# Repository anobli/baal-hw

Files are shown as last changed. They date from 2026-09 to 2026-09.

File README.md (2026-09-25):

# Beal

Beal is a **LoRa valve-control proxy** that retrofits an existing irrigation
controller with remote, wire-free zone control.

## Why

Irrigation controllers are typically wire-only: reaching a new zone, or a
valve far from the controller box, means trenching new low-voltage wiring
across a working field — labor-intensive and disruptive.

Beal solves that wiring problem: clip a **RX** unit onto the existing
controller (no new wiring, no controller replacement) and place **TX** units
directly at the valves; they talk over LoRa, so control reaches valves
without trenching.

## How it works

Two dedicated boards make up one system:

| Board | Role | What it does |
| --- | --- | --- |
| [**Beal-Rx**](Beal-Rx/README.md) | Input | Clips onto the existing controller's zone-output wiring, senses which zone it's energizing, and reports over LoRa. Acts as the LoRa coordinator. |
| [**Beal-TX**](Beal-TX/README.md) | Output | Lives out at the valves, powered by its own battery + solar supply. Drives valve solenoids on command from Beal-Rx. Acts as a LoRa peer. |

```mermaid
flowchart TD
    VC["Existing valve controller<br/>(zone outputs)"] -->|wired, no new cabling| RX["Beal-Rx<br/>LoRa coordinator"]
    RX -->|LoRa P2P, star topology| TX1["Beal-TX #1<br/>LoRa peer"]
    RX -->|LoRa P2P, star topology| TX2["Beal-TX #2<br/>LoRa peer"]
    TX1 -->|wired| V1["Valves — zone A"]
    TX2 -->|wired| V2["Valves — zone B"]
```

The link between Beal-Rx and Beal-TX units is point-to-point LoRa, not
LoRaWAN: a custom, open-source stack with a star topology. Beal-Rx is the
coordinator — it's where commands originate and it's already the central
device by virtue of being wired to the existing controller. Beal-TX units are
peer nodes that take commands from it. LoRaWAN is deliberately avoided for
now — it would require network-server infrastructure disproportionate to
stand up and operate for this product.

## Repository layout

| Folder | What it is |
| --- | --- |
| [`Beal-Rx/`](Beal-Rx/README.md) | Input board: KiCad project, schematics, PCB. |
| [`Beal-TX/`](Beal-TX/README.md) | Output board: KiCad project, schematics, PCB. |
| `Beal-Common/` | Reusable elements shared between boards — currently footprints, with symbol libraries and design blocks planned. |

Schematic PDFs and BOMs are generated automatically on every push via
[`.github/workflows/kicad-schematic-pdf.yml`](.github/workflows/kicad-schematic-pdf.yml).

## What's next: Beal Controller

Both boards share the same LoRa-E5-centric approach, which is also the seed
for a future third board — tentatively **Beal Controller**. It would be a
smart irrigation controller with its own valve outputs and smart features
(weather-driven scheduling, ET0 computation, local web UI), while still able
to control remote valves over LoRa through a Beal-TX unit — replacing the
third-party controller entirely instead of just retrofitting it. This is a
future direction, not yet designed.

## License

Hardware design files are licensed under the
[CERN Open Hardware Licence Version 2 - Strongly Reciprocal](LICENSE).

## Open items

- [ ] Battery chemistry/capacity for the Beal-TX power pack — not yet sized.
- [ ] Enclosure — to do, no design started.
- [ ] Regulatory/certification path for the radio — not started; complicated
      by the use of a custom (non-LoRaWAN) PHY/MAC stack.
- [ ] Unit cost target (below 250 € incl. VAT) — needs re-costing against the
      current RX/TX design.
- [ ] Beal Controller — not designed yet; see above.

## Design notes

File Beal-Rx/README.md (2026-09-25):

# Beal-Rx — input board

Beal-Rx clips onto an existing irrigation controller's zone-output wiring,
senses which zone it's energizing, and reports that over LoRa to one or more
[Beal-TX](../Beal-TX/README.md) units. It is the LoRa coordinator of a Beal
system — it's where commands originate, and it's already the natural central
device since it's the one wired to the existing controller.

The schematic is split into three sheets: **Inputs**, **Radio**, **Power**.

## Inputs (`io_ext.kicad_sch`)

- 12 sense channels, each isolated from the field wiring by an opto-isolator
  (3× LTV-844S, 4 channels each). This gives galvanic isolation from whatever
  the existing controller puts on its zone outputs, with no current drawn
  from or injected back into the controller.
- Sized against 24VAC zone outputs but tolerant of smaller signals
  (9VAC/9VDC), so the same board can read other controller types without a
  hardware change.
- A 14-position terminal block (`TBL004-508-14BE-2GY`) brings in the 12
  channels plus the shared `INPUT_COM` return.
- A dedicated **STM32C031K6Ux MCU** on this sheet scans all 12 opto outputs
  and reports state changes up to the LoRa-E5 (I2C/UART, plus an interrupt
  line) — the LoRa-E5 doesn't have enough spare GPIOs to read 12 channels
  directly itself, so this small companion MCU owns the input-scanning job.
  It has its own SWD (TC2050) connector for programming/debug.

## Radio (`radio_mcu.kicad_sch`)

- **LoRa-E5 module** (U5, Seeed, STM32WL-based) — the application MCU. It
  owns the LoRa radio, drives the status LED (D3), reads the pairing button
  (SW2, on its own dedicated GPIO), and talks to the Inputs sheet's
  STM32C031 over I2C/UART to learn which zone just turned on.
- Pairing button (SW2) behavior:
  - Short press: pairs this coordinator with a Beal-TX peer (implemented).
  - Double press: maps a specific input channel to a specific output channel
    on a specific Beal-TX (planned, procedure still TBD).
  - Long press: probable factory reset (not decided).
- U.FL/antenna connector (J1) for the 868 MHz antenna.
- USB-C connector (J5) — power input only.
- SWD (Tag-Connect J7) for programming/debugging the LoRa-E5.
- One extension connector (J2, `Conn_02x04_Odd_Even`) reserved for a future
  add-on board (e.g. more sense inputs) — not used by anything today.

## Power (`power.kicad_sch`)

- `TPSM863253` buck power module producing the board's logic-level rail from
  USB 5V. No boost converter or valve driver on this board — Beal-Rx only
  senses, it never drives anything, so it has no need for the 9V drive rail
  that Beal-TX needs.
- Powered from a 5V USB supply (mains-adapter or similar) — it lives next to
  the existing controller, which typically has power available nearby.

## Open items

- [ ] Channel-to-channel mapping procedure (input on Beal-Rx → output on a
      specific Beal-TX) — design not finalized.
- [ ] Long-press button behavior (factory reset) — not decided.
- [ ] Extension connector (J2) use case — reserved, nothing designed against
      it yet.

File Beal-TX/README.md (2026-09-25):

# Beal-TX — output board

Beal-TX lives out in the field at the valves, powered by its own battery +
solar supply. It receives commands over LoRa from a [Beal-Rx](../Beal-Rx/README.md)
unit and drives valve solenoids accordingly. It is a LoRa peer node — it has
no wired connection to the existing controller, and only acts on commands
sent by the coordinator.

The schematic is split into three sheets: **I/O Ext Board Output**
(`input.kicad_sch` — the sheet name is more accurate than the filename,
which is a naming leftover), **Radio_MCU**, **Power**.

## I/O Ext Board Output (`input.kicad_sch`)

- **DRV8912QPWPRQ1** (U6) — a 12-channel automotive smart driver, controlled
  directly by the LoRa-E5 over SPI (`SDI`/`SDO`/`SCLK`/`SCS_N`), with
  `SLEEP_N`/`FAULT_N` handshake lines. There is no companion MCU on this
  board — unlike Beal-Rx's Inputs sheet, the LoRa-E5 talks to the driver
  itself.
- 3 valve output channels (`OUTPUT1`–`OUTPUT3`), each driven as a full
  H-bridge — not a shared-common topology. Each DRV8912 half-bridge is
  limited to 1A RMS, which isn't enough for the target valves, so each side
  of a valve's H-bridge is actually two DRV8912 half-bridges wired in
  parallel for extra current headroom. That's 4 half-bridges per valve
  (2 for the P side, 2 for the N side), which is why the driver's 12
  channels only yield 3 valve outputs rather than 6. Target valves are 9VDC
  latching solenoids (a latching valve needs only a brief pulse of the
  correct polarity to switch, then holds its position with no power
  applied — a good fit for a battery/solar-powered field unit).
- 3 status LEDs (`LED1`–`LED3`), one per valve channel.
- Field wiring lands on a 6-position screw terminal (J6, `691401710006B`) —
  6 pins for the 3 valve channels' P/N pairs.
- Fault detection matters more here than in a typical hobby project: a
  stuck-open or undetected-failed valve can waste water or damage a crop.
  Careful use of the DRV8912's `FAULT_N` reporting is a design requirement,
  not a nice-to-have.

## Radio_MCU (`radio_mcu.kicad_sch`)

- **LoRa-E5 module** (U5, Seeed, STM32WL-based) — the application MCU. It
  owns the LoRa radio, drives the status LED, reads the pairing button, and
  drives the DRV8912 directly over SPI.
- Pairing button behavior mirrors Beal-Rx:
  - Short press: pairs this peer with a Beal-Rx coordinator (implemented).
  - Double press: maps a specific output channel to a specific input channel
    on the paired Beal-Rx (planned, procedure still TBD).
  - Long press: probable factory reset (not decided).
- U.FL/antenna connector for the 868 MHz antenna.
- SWD (Tag-Connect) for programming/debugging the LoRa-E5.
- Two extension connectors (`Conn_02x04_Odd_Even`) reserved for future
  add-on boards — not used by anything today. Planned (not yet designed)
  candidates:
  - a sensor input module (flow meter, humidity sensor);
  - a second MCU board with an ESP32, adding smart features and WiFi/BT
    connectivity;
  - possibly an output-expansion board, to drive more than 3 valves from one
    Beal-TX.

## Power (`power.kicad_sch`)

- `TPSM863253` buck power module for the board's logic-level rail.
- `LM5157-Q1` (gated by `9V_EN`) boosts up to 9V to feed the DRV8912 — the
  drive voltage the target latching solenoid valves need for a latch pulse.
- Powered from a battery + solar pack, delivered to the board as 5V over the
  same USB-C connector type used on Beal-Rx (the board only sees a `VBUS`
  net — battery/solar sourcing happens in the external power pack).
- Automotive-grade parts are used deliberately, not for automotive
  compliance but because the board sits in an outdoor enclosure that can see
  high internal temperatures from direct sun exposure — automotive parts
  give margin on temperature rating (and generally ESD/robustness) that
  consumer-grade parts don't.

## Open items

- [ ] Channel-to-channel mapping procedure — design not finalized (shared
      with Beal-Rx, see its README).
- [ ] Long-press button behavior (factory reset) — not decided.
- [ ] Both extension connectors — reserved for planned add-on boards
      (sensor input module, ESP32 MCU board, output-expansion board), none
      designed yet.
- [ ] Battery chemistry/capacity for the power pack — not yet sized.

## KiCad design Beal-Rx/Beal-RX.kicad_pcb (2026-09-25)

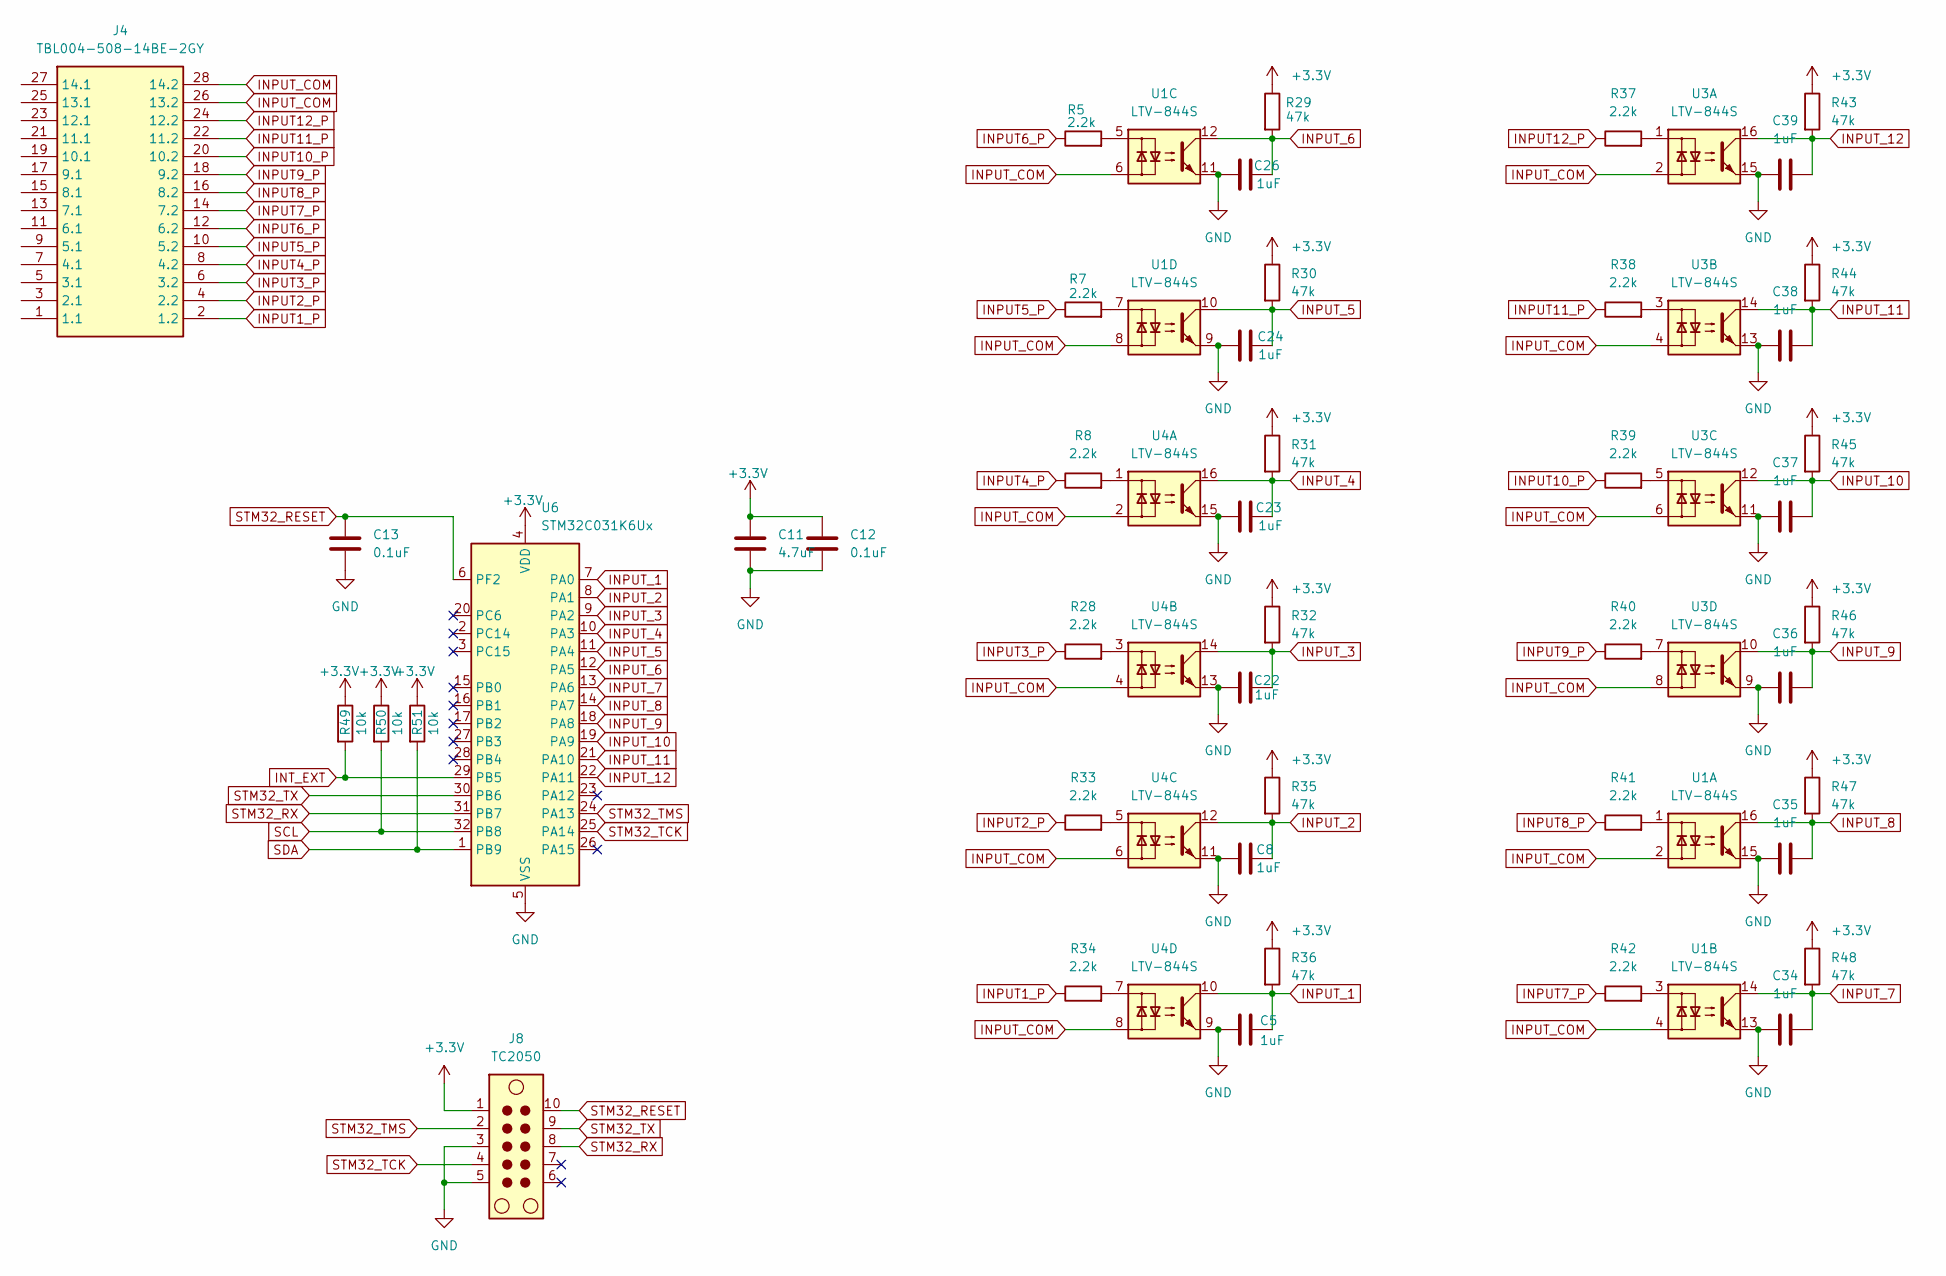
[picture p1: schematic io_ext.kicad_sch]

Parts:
C5, C8, C22, C23, C24, C26, C34, C35, C36, C37, C38, C39: 1uF; C_0603_1608Metric; Manufacturer_Part_Number 1uF 16V 0603
C11: 4.7uF; C_0805_2012Metric; MPN 4.7uF 10V 0805
C12, C13: 0.1uF; C_0805_2012Metric; MPN 0.1uF 10V 0805
J4: TBL004-508-14BE-2GY; Mouser Part Number 490-TBL00450814BE2GY
J8: TC2050; Tag-Connect_TC2050-IDC-NL_2x05_P1.27mm_Vertical
R5, R7, R8, R28, R33, R34, R37, R38, R39, R40, R41, R42: 2.2k; R_0402_1005Metric; Manufacturer_Part_Number 2.2K 0402
R29, R30, R31, R32, R35, R36, R43, R44, R45, R46, R47, R48: 47k; R_0402_1005Metric; Manufacturer_Part_Number 47K 0402
R49, R50, R51: 10k; R_0402_1005Metric; MPN 10k 0402
U1, U3, U4: LTV-844S; SMDIP-16_W9.53mm; MPN LTV-844S
U6: STM32C031K6Ux; QFN-32-1EP_5x5mm_P0.5mm_EP3.45x3.45mm; MPN STM32C031K6U6

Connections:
+3.3V: C11.1, C12.1, J8.1, R29.1, R30.1, R31.1, R32.1, R35.1, R36.1, R43.1, R44.1, R45.1, R46.1, R47.1, R48.1, R49.1, R50.1, R51.1, U6.4 (VDD); also elsewhere on the board
GND: C5.1, C8.2, C11.2, C12.2, C13.2, C22.1, C23.1, C24.2, C26.2, C34.1, C35.1, C36.1, C37.1, C38.2, C39.1, J8.3, J8.5, U1.9, U1.11, U1.13, U1.15, U3.9, U3.11, U3.13, U3.15, U4.9, U4.11, U4.13, U4.15, U6.5 (VSS), U6.33 (VSS); also elsewhere on the board
INPUT1_P: J4.2 (1.2), R34.1
INPUT2_P: J4.4 (2.2), R33.1
INPUT3_P: J4.6 (3.2), R28.1
INPUT4_P: J4.8 (4.2), R8.1
INPUT5_P: J4.10 (5.2), R7.1
INPUT6_P: J4.12 (6.2), R5.1
INPUT7_P: J4.14 (7.2), R42.1
INPUT8_P: J4.16 (8.2), R41.1
INPUT9_P: J4.18 (9.2), R40.1
INPUT10_P: J4.20 (10.2), R39.1
INPUT11_P: J4.22 (11.2), R38.1
INPUT12_P: J4.24 (12.2), R37.1
INPUT_1: C5.2, R36.2, U4.10, U6.7 (PA0)
INPUT_2: C8.1, R35.2, U4.12, U6.8 (PA1)
INPUT_3: C22.2, R32.2, U4.14, U6.9 (PA2)
INPUT_4: C23.2, R31.2, U4.16, U6.10 (PA3)
INPUT_5: C24.1, R30.2, U1.10, U6.11 (PA4)
INPUT_6: C26.1, R29.2, U1.12, U6.12 (PA5)
INPUT_7: C34.2, R48.2, U1.14, U6.13 (PA6)
INPUT_8: C35.2, R47.2, U1.16, U6.14 (PA7)
INPUT_9: C36.2, R46.2, U3.10, U6.18 (PA8)
INPUT_10: C37.2, R45.2, U3.12, U6.19 (PA9)
INPUT_11: C38.1, R44.2, U3.14, U6.21 (PA10)
INPUT_12: C39.2, R43.2, U3.16, U6.22 (PA11)
INPUT_COM: J4.26 (13.2), J4.28 (14.2), U1.2, U1.4, U1.6, U1.8, U3.2, U3.4, U3.6, U3.8, U4.2, U4.4, U4.6, U4.8
INT_EXT: R49.2, U6.29 (PB5); also elsewhere on the board
unnamed: R5.2, U1.5
unnamed: R7.2, U1.7
unnamed: R8.2, U4.1
unnamed: R28.2, U4.3
unnamed: R33.2, U4.5
unnamed: R34.2, U4.7
unnamed: R37.2, U3.1
unnamed: R38.2, U3.3
unnamed: R39.2, U3.5
unnamed: R40.2, U3.7
unnamed: R41.2, U1.1
unnamed: R42.2, U1.3
SCL: R50.2, U6.32 (PB8); also elsewhere on the board
SDA: R51.2, U6.1 (PB9); also elsewhere on the board
STM32_RESET: C13.1, J8.10, U6.6 (PF2)
STM32_RX: J8.8, U6.31 (PB7)
STM32_TCK: J8.4, U6.25 (PA14)
STM32_TMS: J8.2, U6.24 (PA13)
STM32_TX: J8.9, U6.30 (PB6)

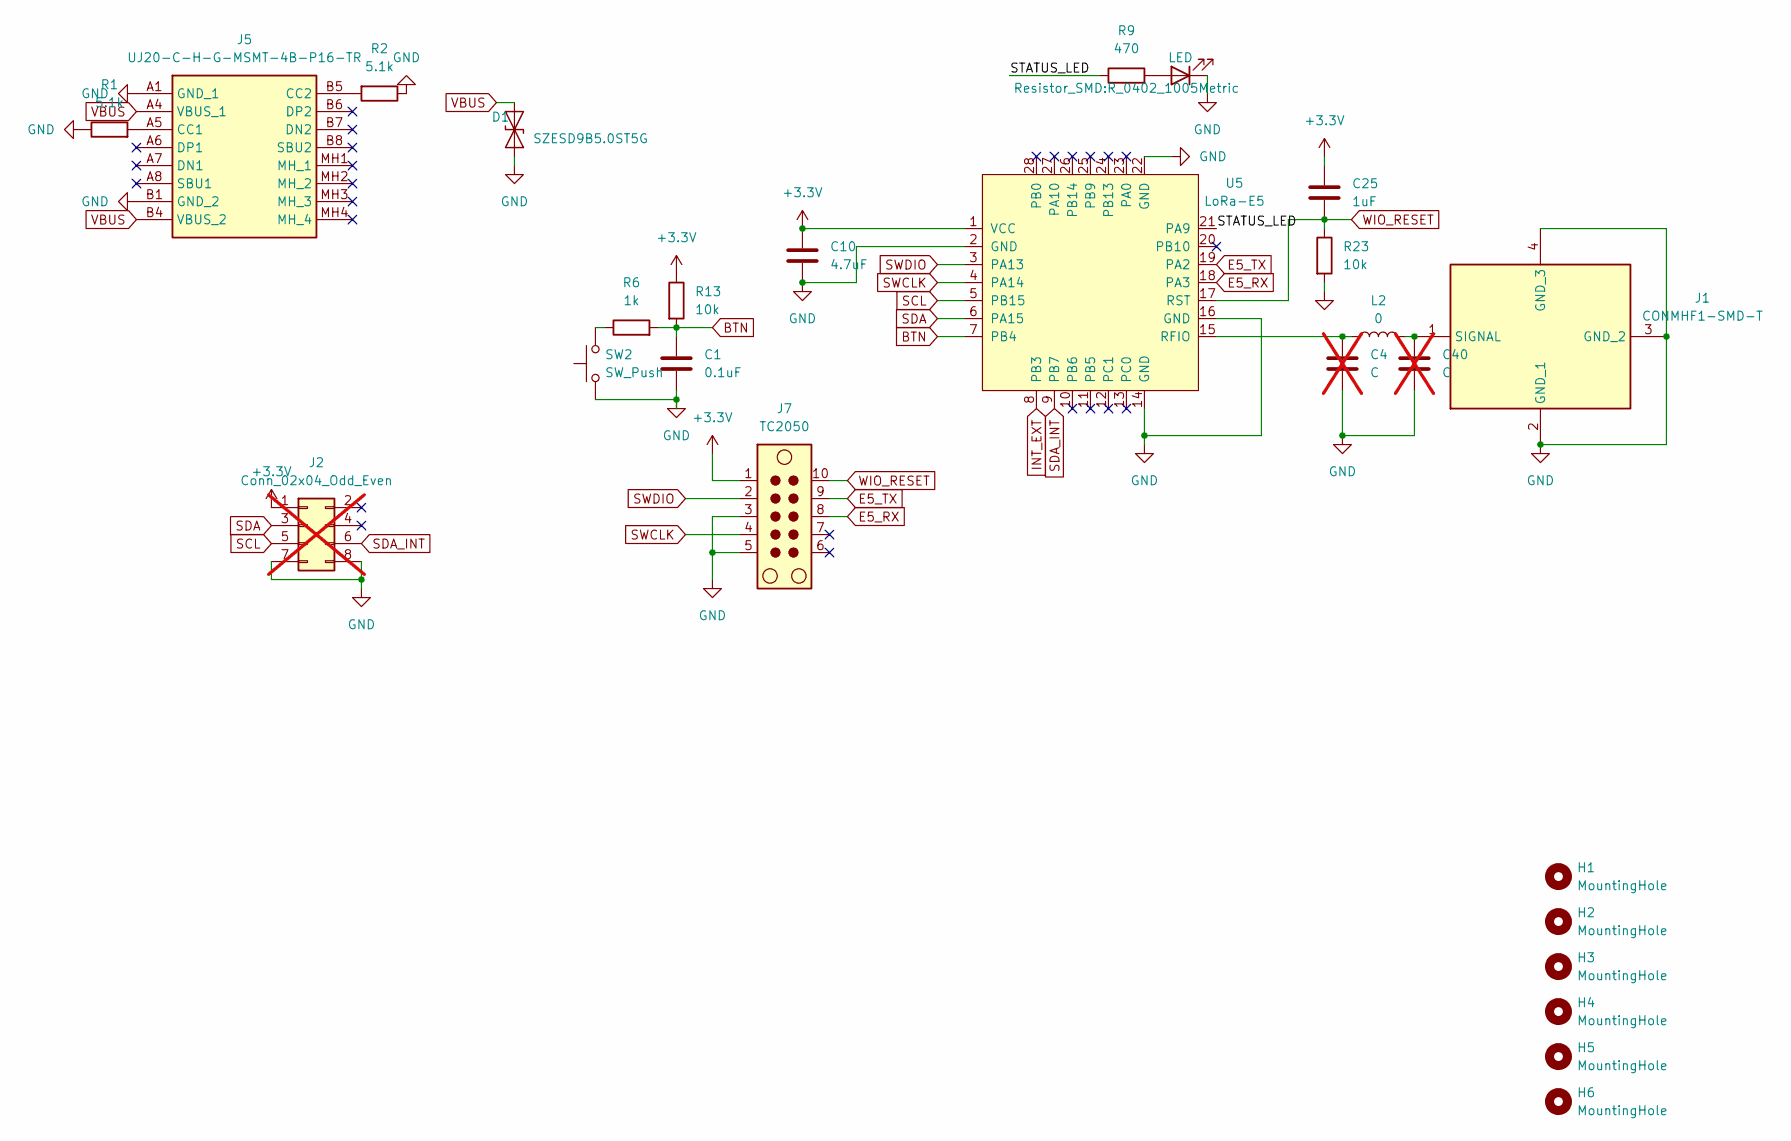
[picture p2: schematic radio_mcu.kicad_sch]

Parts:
C1: 0.1uF; C_0805_2012Metric; MPN 0.1uF 16V 0805
C4, C40: C; C_0603_1608Metric; not fitted
C10: 4.7uF; C_0805_2012Metric; MPN 4.7uF 10V 0805
C25: 1uF; C_0603_1608Metric; Manufacturer_Part_Number 1uF 16V 0603
D1: SZESD9B5.0ST5G; D_SOD-923; MPN SZESD9B5.0ST5G
D3: LED; LED_0603_1608Metric; Manufacturer_Part_Number led red 1206
H1, H2, H3, H4, H5, H6: MountingHole; MountingHole_2.1mm
J1: CONMHF1-SMD-T; CONMHF1SMDT; Mouser Part Number 712-CONMHF1-SMD-T
J2: Conn_02x04_Odd_Even; PinHeader_2x04_P1.00mm_Vertical_SMD; not fitted
J5: UJ20-C-H-G-MSMT-4B-P16-TR; UJ20CHGMSMT4BP16TR; Manufacturer_Part_Number UJ20-C-H-G-MSMT-4B-P16-TR
J7: TC2050; Tag-Connect_TC2050-IDC-NL_2x05_P1.27mm_Vertical
L2: 0; L_0603_1608Metric; Manufacturer_Part_Number 0K 0603
R1, R2: 5.1k; R_0402_1005Metric; Manufacturer_Part_Number 5.1K 0402
R6: 1k; R_0402_1005Metric; MPN 1K 0402
R9: 470; R_0402_1005Metric; MPN 470 0402
R13: 10k; R_0402_1005Metric; MPN 10K 0402
R23: 10k; R_0402_1005Metric; Manufacturer_Part_Number 10K 0402
SW2: SW_Push; SW_Tactile_SPST_Angled_PTS645Vx83-2LFS
U5: LoRa-E5; MPN LORA-E5 LORAWAN MODULE

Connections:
+3.3V: C10.1, C25.1, J2.1, J7.1, R13.1, U5.1 (VCC); also elsewhere on the board
/Radio/STATUS_LED: R9.1, U5.21 (PA9)
BTN: C1.1, R6.2, R13.2, U5.7 (PB4)
E5_RX: J7.8, U5.18 (PA3)
E5_TX: J7.9, U5.19 (PA2)
GND: C1.2, C4.2, C10.2, C40.2, D1.1 (A1), D3.1 (K), J1.2 (GND_1), J1.3 (GND_2), J1.4 (GND_3), J2.7, J2.8, J5.A1 (GND_1), J5.B1 (GND_2), J7.3, J7.5, R1.1, R2.1, R23.2, SW2.1, U5.2 (GND), U5.14 (GND), U5.16 (GND), U5.22 (GND); also elsewhere on the board
INT_EXT: U5.8 (PB3); also elsewhere on the board
unnamed: D3.2 (A), R9.2
unnamed: C40.1, J1.1 (SIGNAL), L2.2
unnamed: J5.A5 (CC1), R1.2
unnamed: J5.B5 (CC2), R2.2
unnamed: R6.1, SW2.2
unnamed: C4.1, L2.1, U5.15 (RFIO)
SCL: J2.5, U5.5 (PB15); also elsewhere on the board
SDA: J2.3, U5.6 (PA15); also elsewhere on the board
SDA_INT: J2.6, U5.9 (PB7)
SWCLK: J7.4, U5.4 (PA14)
SWDIO: J7.2, U5.3 (PA13)
VBUS: D1.2 (A2), J5.A4 (VBUS_1), J5.B4 (VBUS_2); also elsewhere on the board
WIO_RESET: C25.2, J7.10, R23.1, U5.17 (RST)

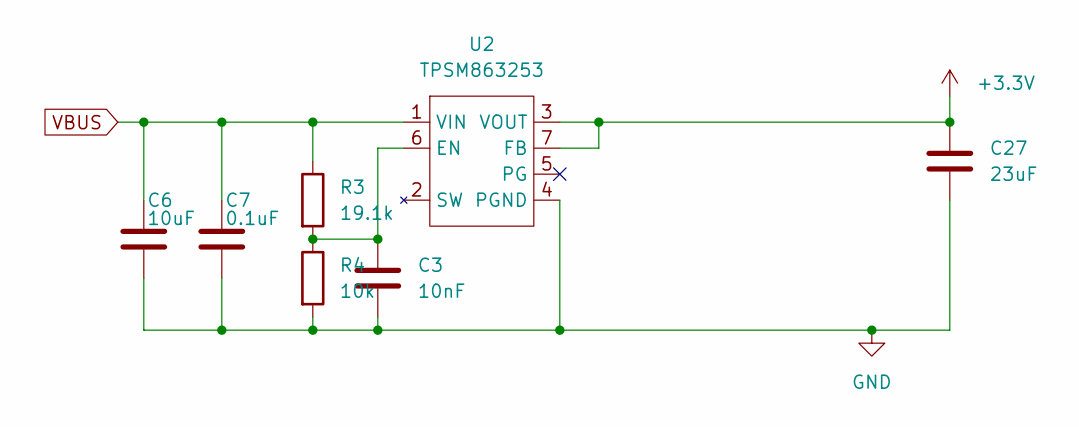
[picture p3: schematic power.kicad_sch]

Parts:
C3: 10nF; C_0402_1005Metric; Manufacturer_Part_Number GRM155R71C103KA01D
C6: 10uF; C_0805_2012Metric; Manufacturer_Part_Number C0805C106K8PACTU
C7: 0.1uF; C_0805_2012Metric; Manufacturer_Part_Number 08053C104KAT2A
C27: 23uF; C_0805_2012Metric; Manufacturer_Part_Number MSASL219LB5226MTNA01
R3: 19.1k; R_0402_1005Metric; Manufacturer_Part_Number CRCW040219K1FKED
R4: 10k; R_0402_1005Metric; Manufacturer_Part_Number CRCW040210K0FKED
U2: TPSM863253; Texas_RDX0007A_QFN-FCMOD-7-3.3x4mm-P0.5mm_4EP; MPN TPSM863253RDXR

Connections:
+3.3V: C27.1, U2.3 (VOUT), U2.7 (FB); also elsewhere on the board
GND: C3.2, C6.2, C7.2, C27.2, R4.2, U2.4 (PGND); also elsewhere on the board
unnamed: C3.1, R3.2, R4.1, U2.6 (EN)
VBUS: C6.1, C7.1, R3.1, U2.1 (VIN); also elsewhere on the board

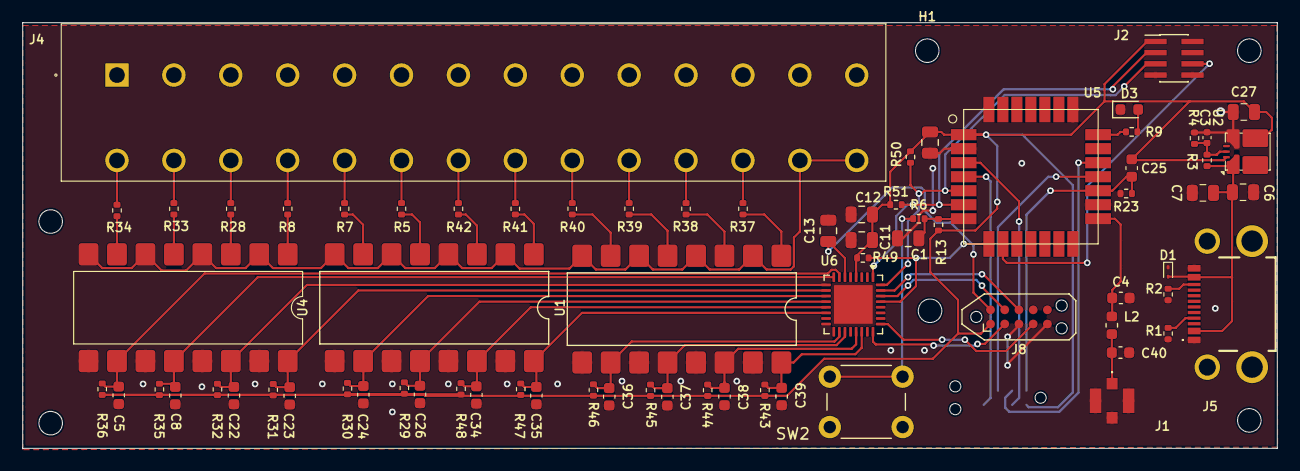
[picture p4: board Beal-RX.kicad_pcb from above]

Board: 2 copper layers, 112.0 x 38.0 mm, 81 parts (1 on the bottom side), 63 nets.

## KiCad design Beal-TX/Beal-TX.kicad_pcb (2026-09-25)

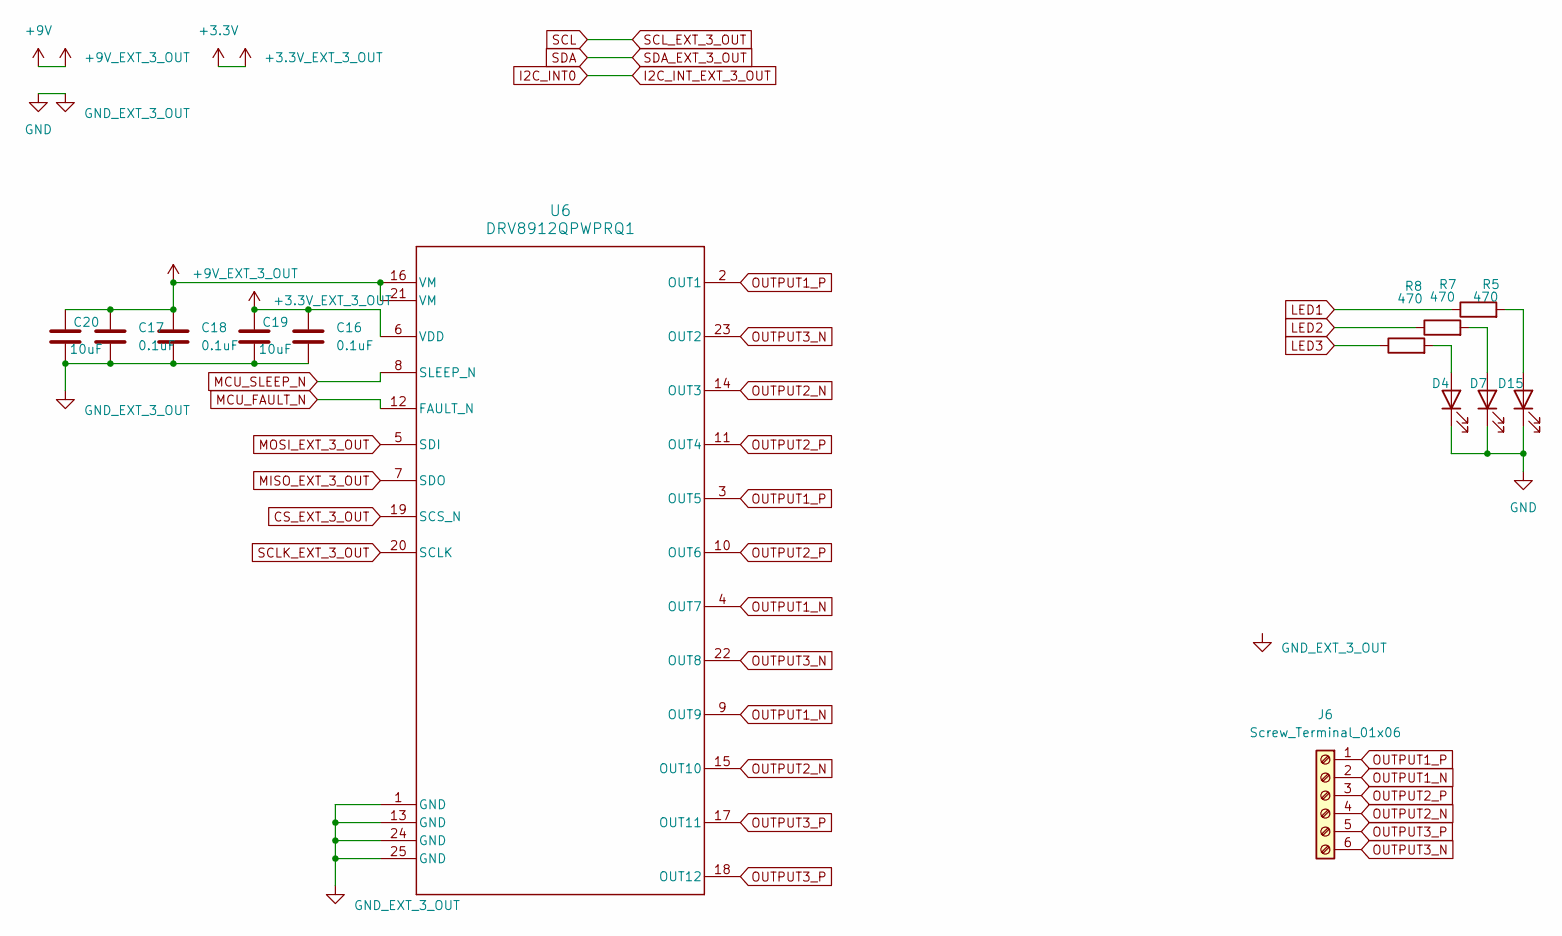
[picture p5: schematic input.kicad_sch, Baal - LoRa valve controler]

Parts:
C16: 0.1uF; C_0402_1005Metric; Manufacturer_Part_Number 0,1uF 16V 0402
C17, C18: 0.1uF; C_0805_2012Metric; Manufacturer_Part_Number 0,1uF 50V 0805
C19: 10uF; C_0805_2012Metric; MPN 10uF 10V 0805
C20: 10uF; R_1206_3216Metric; MPN GRM31CR71C106KAC7L
D4, D7, D15: LED; LED_0603_1608Metric; Manufacturer_Part_Number led red 1206
J6: Screw_Terminal_01x06; 691401710006B; MPN 691401710006B
R5: 470; R_0402_1005Metric
R7, R8: 470; R_0402_1005Metric; MPN 470 0402
U6: DRV8912QPWPRQ1; HTSSOP-24-1EP_4.4x7.8mm_P0.65mm_EP3.4x7.8mm_Mask2.4x4.68mm_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; Manufacturer_Part_Number DRV8912QPWPRQ1

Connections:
+3.3V: C16.1, C19.1, U6.6 (VDD); also elsewhere on the board
+9V: C17.1, C18.1, C20.1, U6.16 (VM), U6.21 (VM); also elsewhere on the board
CS_EXT_3_OUT: U6.19 (SCS_N); also elsewhere on the board
GND: C16.2, C17.2, C18.2, C19.2, C20.2, D4.1 (K), D7.1 (K), D15.1 (K), U6.1 (GND), U6.13 (GND), U6.24 (GND), U6.25 (GND); also elsewhere on the board
LED1: R5.1; also elsewhere on the board
LED2: R7.1; also elsewhere on the board
LED3: R8.1; also elsewhere on the board
MCU_FAULT_N: U6.12 (FAULT_N); also elsewhere on the board
MCU_SLEEP_N: U6.8 (SLEEP_N); also elsewhere on the board
MISO_EXT_3_OUT: U6.7 (SDO); also elsewhere on the board
MOSI_EXT_3_OUT: U6.5 (SDI); also elsewhere on the board
unnamed: D4.2 (A), R8.2
unnamed: D7.2 (A), R7.2
unnamed: D15.2 (A), R5.2
OUTPUT1_N: J6.2, U6.4 (OUT7), U6.9 (OUT9)
OUTPUT1_P: J6.1, U6.2 (OUT1), U6.3 (OUT5)
OUTPUT2_N: J6.4, U6.14 (OUT3), U6.15 (OUT10)
OUTPUT2_P: J6.3, U6.10 (OUT6), U6.11 (OUT4)
OUTPUT3_N: J6.6, U6.22 (OUT8), U6.23 (OUT2)
OUTPUT3_P: J6.5, U6.17 (OUT11), U6.18 (OUT12)
SCLK_EXT_3_OUT: U6.20 (SCLK); also elsewhere on the board

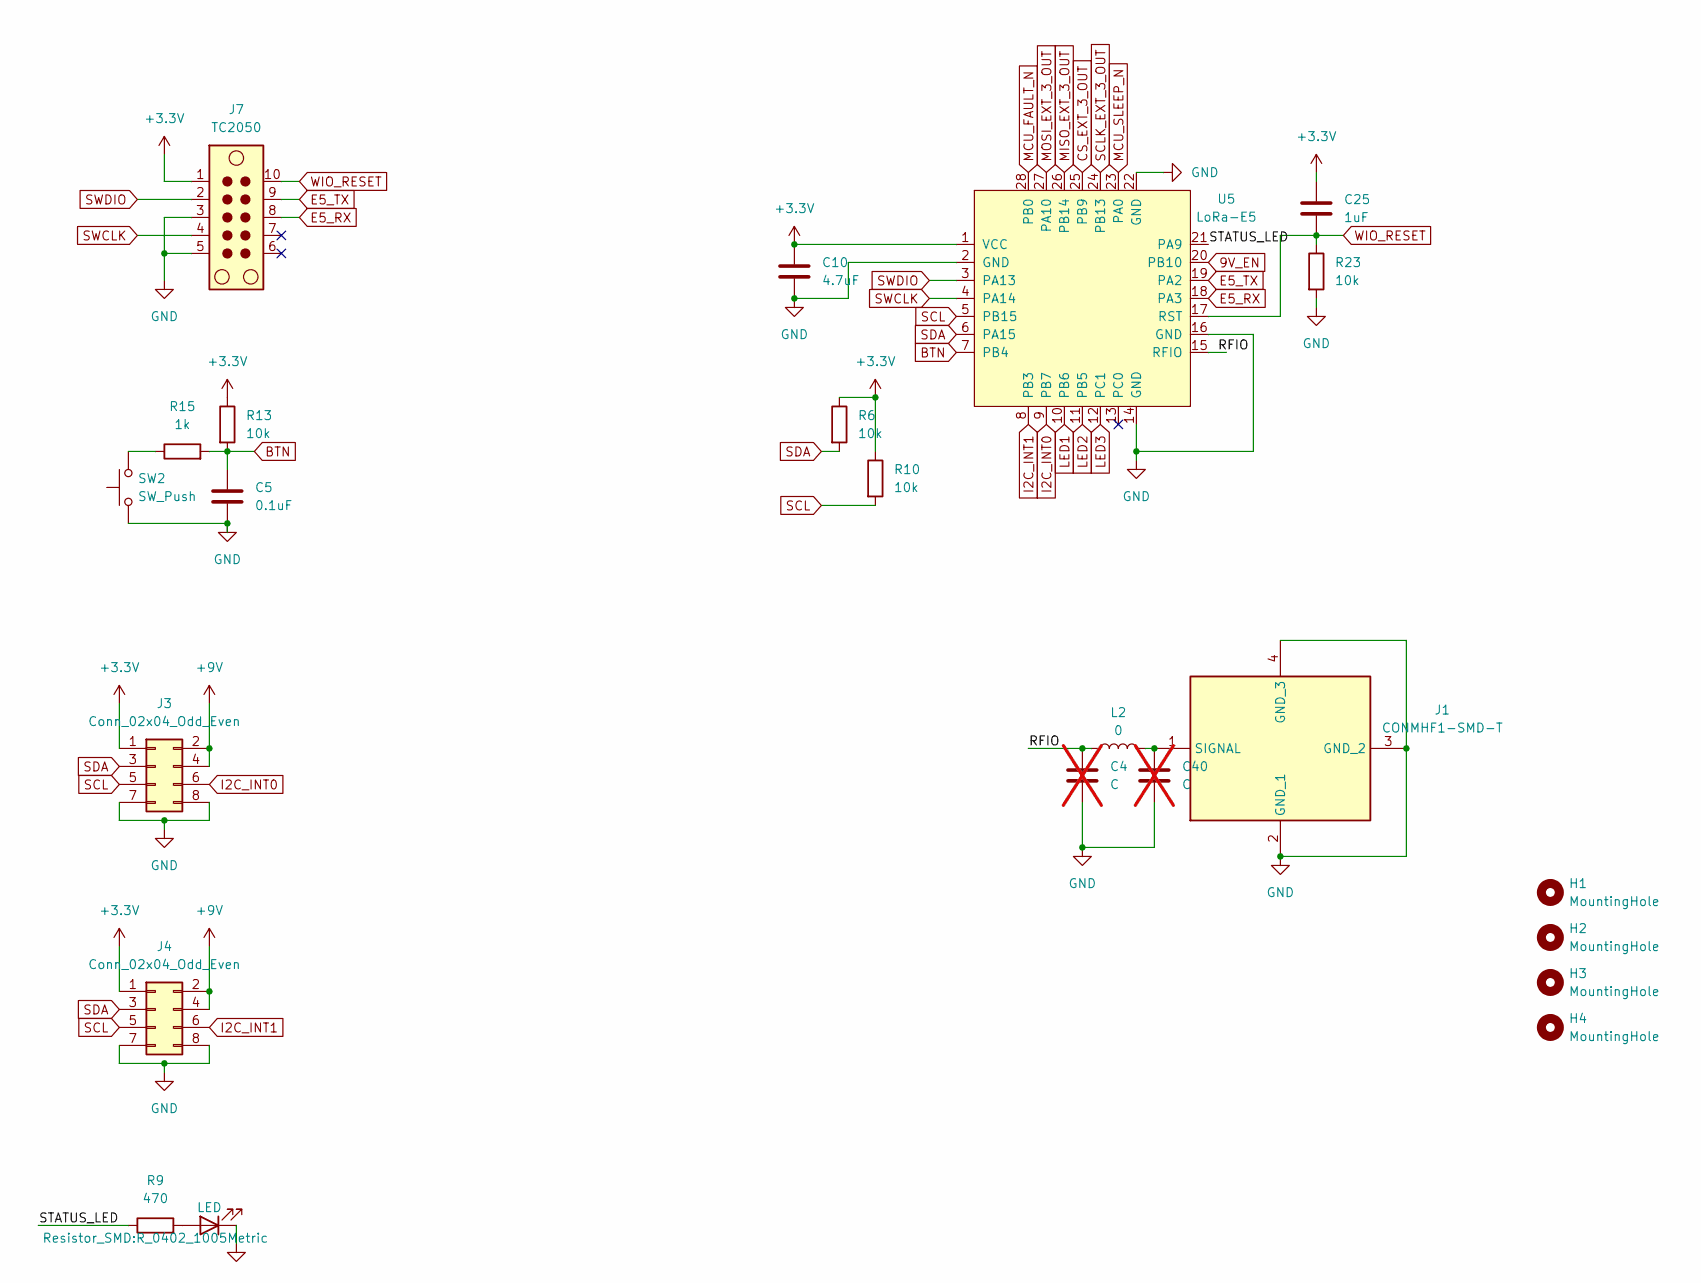
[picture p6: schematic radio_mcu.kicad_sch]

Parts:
C4, C40: C; C_0603_1608Metric; not fitted
C5: 0.1uF; C_0805_2012Metric; MPN 10uF 16V 0805
C10: 4.7uF; C_0805_2012Metric; MPN 4.7uF 10V 0805
C25: 1uF; C_0603_1608Metric; Manufacturer_Part_Number 1uF 16V 0603
D3: LED; LED_0603_1608Metric; Manufacturer_Part_Number led red 1206
H1, H2, H3, H4: MountingHole; MountingHole_2.1mm
J1: CONMHF1-SMD-T; CONMHF1SMDT; Mouser Part Number 712-CONMHF1-SMD-T
J3, J4: Conn_02x04_Odd_Even; PinHeader_2x04_P1.00mm_Vertical_SMD
J7: TC2050; Tag-Connect_TC2050-IDC-NL_2x05_P1.27mm_Vertical
L2: 0; L_0603_1608Metric; MPN RC0603FR-100RL
R6, R10: 10k; R_0402_1005Metric; MPN 10k 0402
R9: 470; R_0402_1005Metric; MPN 470 0402
R13: 10k; R_0402_1005Metric; MPN 10K 0402
R15: 1k; R_0402_1005Metric; MPN 1k 0402
R23: 10k; R_0402_1005Metric; Manufacturer_Part_Number 10K 0402
SW2: SW_Push; SW_PUSH_6mm; MPN TS02-66-43-BK-160-LCR-D
U5: LoRa-E5; MPN LORA-E5 LORAWAN MODULE

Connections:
9V_EN: U5.20 (PB10); also elsewhere on the board
+3.3V: C10.1, C25.1, J3.1, J4.1, J7.1, R6.1, R10.1, R13.1, U5.1 (VCC); also elsewhere on the board
+9V: J3.2, J3.4, J4.2, J4.4; also elsewhere on the board
/Radio_MCU/RFIO: C4.1, L2.1, U5.15 (RFIO)
/Radio_MCU/STATUS_LED: R9.1, U5.21 (PA9)
BTN: C5.1, R13.2, R15.2, U5.7 (PB4)
CS_EXT_3_OUT: U5.25 (PB9); also elsewhere on the board
E5_RX: J7.8, U5.18 (PA3)
E5_TX: J7.9, U5.19 (PA2)
GND: C4.2, C5.2, C10.2, C40.2, D3.1 (K), J1.2 (GND_1), J1.3 (GND_2), J1.4 (GND_3), J3.7, J3.8, J4.7, J4.8, J7.3, J7.5, R23.2, SW2.1, U5.2 (GND), U5.14 (GND), U5.16 (GND), U5.22 (GND); also elsewhere on the board
I2C_INT0: J3.6, U5.9 (PB7)
I2C_INT1: J4.6, U5.8 (PB3)
LED1: U5.10 (PB6); also elsewhere on the board
LED2: U5.11 (PB5); also elsewhere on the board
LED3: U5.12 (PC1); also elsewhere on the board
MCU_FAULT_N: U5.28 (PB0); also elsewhere on the board
MCU_SLEEP_N: U5.23 (PA0); also elsewhere on the board
MISO_EXT_3_OUT: U5.26 (PB14); also elsewhere on the board
MOSI_EXT_3_OUT: U5.27 (PA10); also elsewhere on the board
unnamed: D3.2 (A), R9.2
unnamed: C40.1, J1.1 (SIGNAL), L2.2
unnamed: R15.1, SW2.2
SCL: J3.5, J4.5, R10.2, U5.5 (PB15)
SCLK_EXT_3_OUT: U5.24 (PB13~); also elsewhere on the board
SDA: J3.3, J4.3, R6.2, U5.6 (PA15)
SWCLK: J7.4, U5.4 (PA14)
SWDIO: J7.2, U5.3 (PA13)
WIO_RESET: C25.2, J7.10, R23.1, U5.17 (RST)

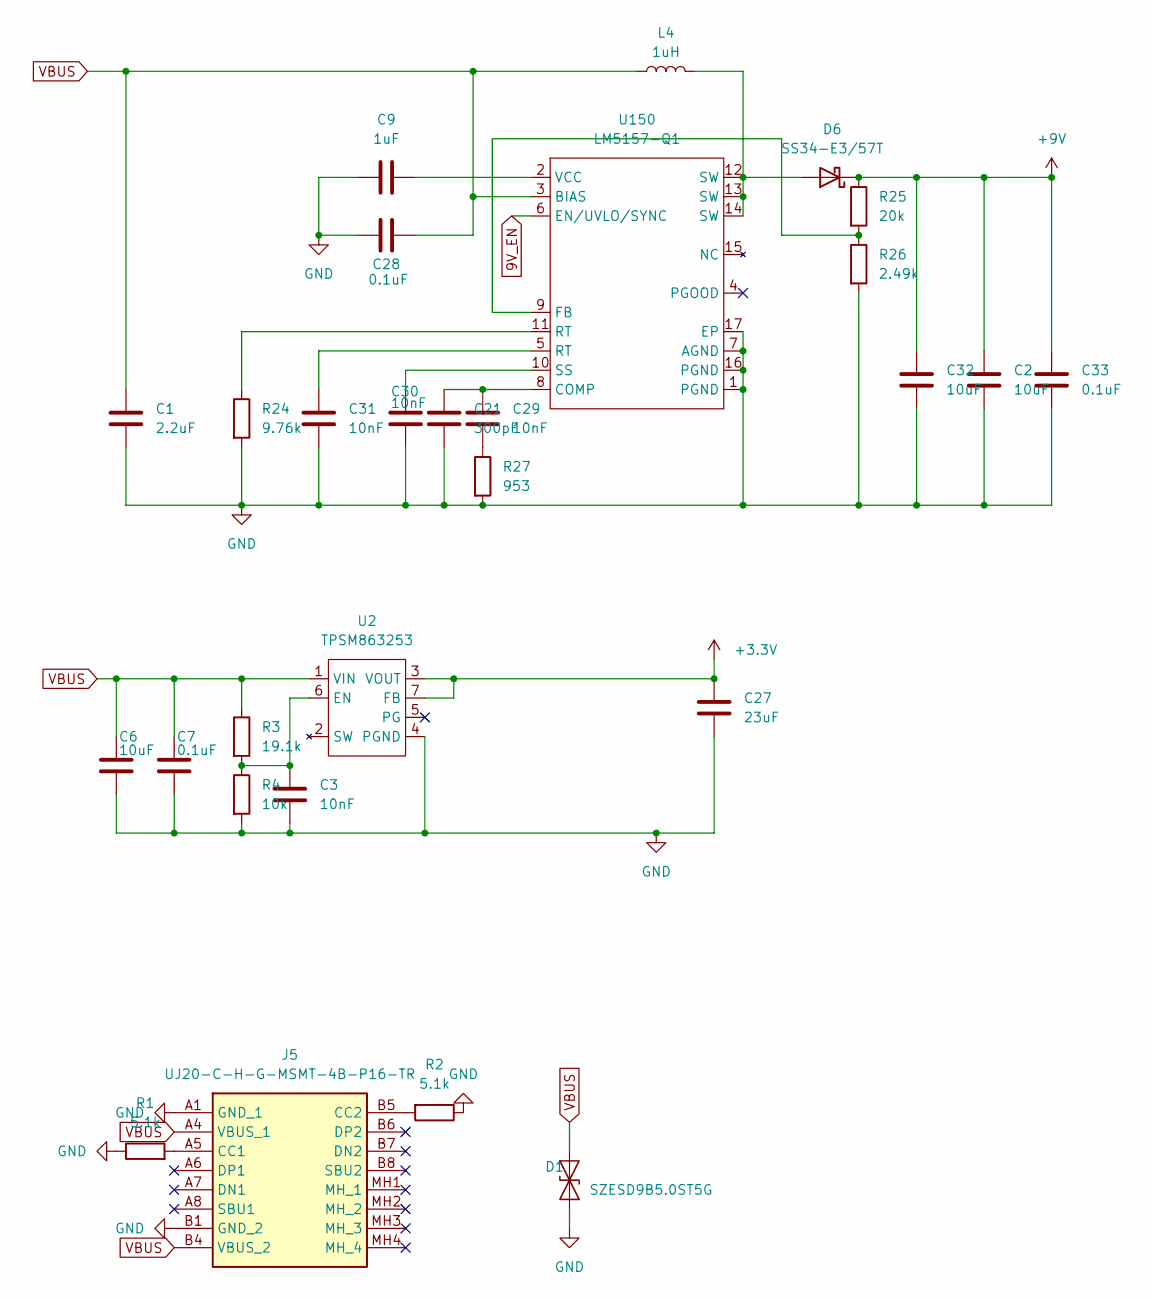
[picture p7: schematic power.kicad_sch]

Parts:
C1: 2.2uF; C_0805_2012Metric; Manufacturer_Part_Number GRM21BR71A225KA01L
C2, C32: 10uF; C_1206_3216Metric; Manufacturer_Part_Number GRM31CR71C106KAC7L
C3: 10nF; C_0402_1005Metric; Manufacturer_Part_Number GRM155R71C103KA01D
C6: 10uF; C_0805_2012Metric; Manufacturer_Part_Number C0805C106K8PACTU
C7: 0.1uF; C_0805_2012Metric; Manufacturer_Part_Number 08053C104KAT2A
C9: 1uF; C_0603_1608Metric; Manufacturer_Part_Number EMK107B7105KA-T
C21: 300pF; C_0402_1005Metric; Manufacturer_Part_Number GRM1555C1E301JA01D
C27: 23uF; C_0805_2012Metric; Manufacturer_Part_Number MSASL219LB5226MTNA01
C28: 0.1uF; C_0402_1005Metric; Manufacturer_Part_Number GRM155R71A104KA01D
C29, C30, C31: 10nF; C_0402_1005Metric; Manufacturer_Part_Number GRM155R70J103KA01D
C33: 0.1uF; C_0805_2012Metric; Manufacturer_Part_Number GRM155R71C104KA88D
D1: SZESD9B5.0ST5G; D_SOD-923; MPN SZESD9B5.0ST5G
D6: SS34-E3/57T; D_SMB; Manufacturer_Part_Number SS34-E3/57T
J5: UJ20-C-H-G-MSMT-4B-P16-TR; UJ20CHGMSMT4BP16TR; Manufacturer_Part_Number UJ20-C-H-G-MSMT-4B-P16-TR
L4: 1uH; L_Wuerth_WE-PD-Typ-7345; Manufacturer_Part_Number 744777001
R1, R2: 5.1k; R_0402_1005Metric; Manufacturer_Part_Number 5.1K 0402
R3: 19.1k; R_0402_1005Metric; Manufacturer_Part_Number CRCW040219K1FKED
R4: 10k; R_0402_1005Metric; Manufacturer_Part_Number CRCW040210K0FKED
R24: 9.76k; R_0402_1005Metric; Manufacturer_Part_Number CRCW04029K76FKED
R25: 20k; R_0402_1005Metric; Manufacturer_Part_Number CRCW040220K0FKED
R26: 2.49k; R_0402_1005Metric; Manufacturer_Part_Number CRCW04022K49FKED
R27: 953; R_0402_1005Metric; Manufacturer_Part_Number CRCW0402953RFKED
U2: TPSM863253; Texas_RDX0007A_QFN-FCMOD-7-3.3x4mm-P0.5mm_4EP; MPN TPSM863253RDXR
U150: LM5157-Q1; WQFN-16-1EP_3x3mm_P0.5mm_EP1.68x1.68mm_ThermalVias; Manufacturer_Part_Number LM5157QRTERQ1

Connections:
9V_EN: U150.6 (EN/UVLO/SYNC); also elsewhere on the board
+3.3V: C27.1, U2.3 (VOUT), U2.7 (FB); also elsewhere on the board
+9V: C2.1, C32.1, C33.1, D6.1 (K), R25.1; also elsewhere on the board
GND: C1.2, C2.2, C3.2, C6.2, C7.2, C9.2, C21.2, C27.2, C28.1, C30.2, C31.2, C32.2, C33.2, D1.1 (A1), J5.A1 (GND_1), J5.B1 (GND_2), R1.1, R2.1, R4.2, R24.2, R26.2, R27.2, U2.4 (PGND), U150.1 (PGND), U150.7 (AGND), U150.16 (PGND), U150.17 (EP); also elsewhere on the board
unnamed: C29.2, R27.1
unnamed: C31.1, U150.5 (RT)
unnamed: D6.2 (A), L4.2, U150.12 (SW), U150.13 (SW), U150.14 (SW)
unnamed: J5.A5 (CC1), R1.2
unnamed: J5.B5 (CC2), R2.2
unnamed: R24.1, U150.11 (RT)
unnamed: C3.1, R3.2, R4.1, U2.6 (EN)
unnamed: C21.1, C29.1, U150.8 (COMP)
unnamed: R25.2, R26.1, U150.9 (FB)
unnamed: C30.1, U150.10 (SS)
unnamed: C9.1, U150.2 (VCC)
VBUS: C1.1, C6.1, C7.1, C28.2, D1.2 (A2), J5.A4 (VBUS_1), J5.B4 (VBUS_2), L4.1, R3.1, U2.1 (VIN), U150.3 (BIAS)

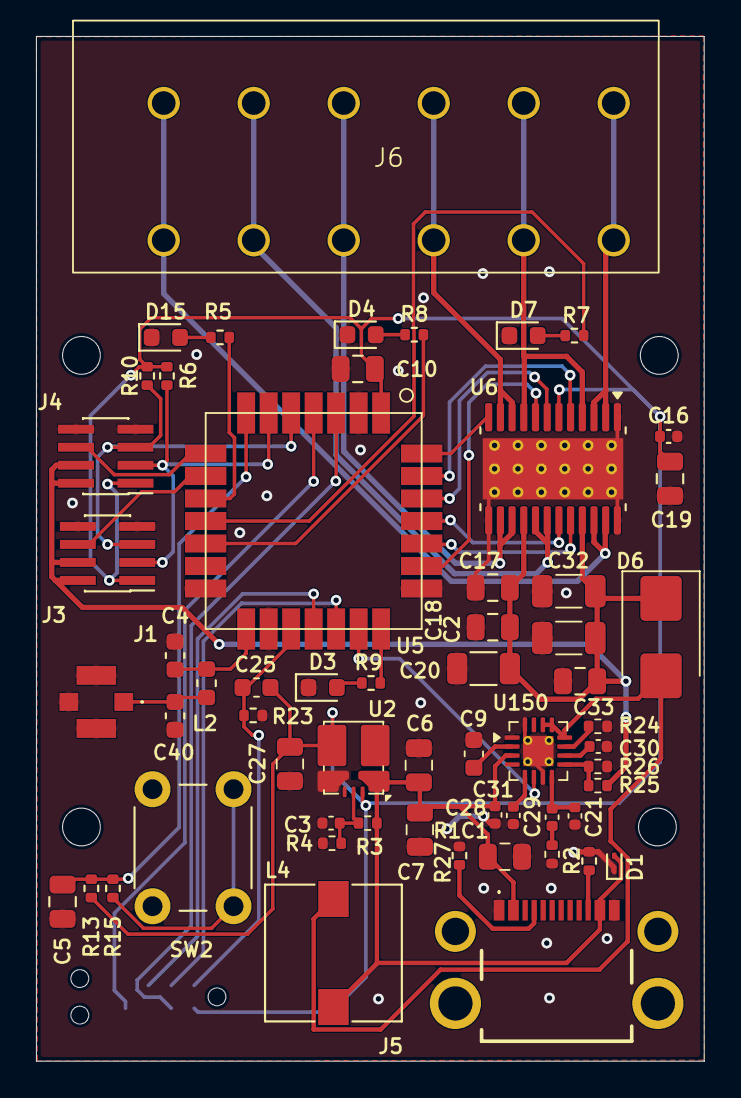
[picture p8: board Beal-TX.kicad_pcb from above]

Board: 2 copper layers, 37.1 x 56.9 mm, 64 parts (1 on the bottom side), 49 nets.

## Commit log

2026-09-25 Add a footprint for 691401710006B screwless connector
    This adds a footprint for 691401710006B screwless connector.
    This has been done following this datasheet:
    https://www.we-online.com/components/products/datasheet/691401710006B.pdf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
2026-09-25 Fork and update WQFN-16 footprint
    The original footprint causes DRC errors when board parameters from
    Aisler are applied.
    This updates the thermal vias' hole to follow Aisler rules.
2026-09-25 Create design file for a LoRa proxy to control remote valves
    This adds design files for the LoRa proxy RX board.
    This board will monitor state of valve controoled by a valve controller
    attached to it and send the state to a remote device over LoRa.
    The device has 12 inputs that could be connected to a 24VAC valve
    but same hardware design should also support valves with different voltages
    (continuous and latch included).
    In addition, the hardware has been designed to also support board extensions
    (to add more input and outpus) or to work alone (e.g. connected to a LoRaWAN)
    network.
    The device must be powered by a 5V USB-C power supply.
    Current limitation / know issue:
    - I used few symbols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
    [Beal-RX.kicad_pcb, Beal-RX.kicad_sch, io_ext.kicad_sch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]
2026-09-25 Create design file for a LoRa proxy to control remote valves
    This add design files for a LoRa proxy TX device, connected to valve
    and replicate state emmited by the remote valve controller over LoRa.
    The device has 3 outputs to control 9VDC valves latch.
    The device must be powered by an USB-C power supply.
    Since the device is going to be in field, this is expected to be powered
    by a solar panel with a battery and USB-C connectivity.
    The device has a boost converter that allow generating 9V voltage
    for controlling the valve.
    - I used few symbols and footprint that I can't redistribute.
    In addition, some are causing a lot of DRC errors.
    I should do my own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
    [Beal-TX.kicad_pcb, Beal-TX.kicad_sch, input.kicad_sch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]
2026-09-25 Add a workflow for generating schematics in PDF format
    This adds a workflow to generate automatically the schematics
    in PDF format which is convenient for people that doesn't want to
    install kicad.
2026-09-25 Update workflow to build the BOM
    This updates the workflow to generate the BOM in addition of schematics.
2026-09-25 Add project and per-board README documentation
    Document the current RX/TX architecture (dedicated input/output boards,
    STM32C031 companion MCU on Beal-Rx, paralleled H-bridge output stage on
    Beal-TX) and the planned Beal Controller board.
